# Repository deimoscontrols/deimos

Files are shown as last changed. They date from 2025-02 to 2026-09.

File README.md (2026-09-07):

# Deimos

|[Website](https://deimoscontrols.com) |\||[Control Program](https://github.com/deimoscontrols/deimos/tree/main/software/deimos) |\|| [Packet Formats](https://github.com/deimoscontrols/deimos/tree/main/software/deimos_shared) |\|| [Firmware](https://github.com/deimoscontrols/deimos/tree/main/firmware) |\|| [Hardware Designs](https://github.com/deimoscontrols/deimos/tree/main/hardware) |
|---|-|---|-|---|-|---|-----|-|

Realtime data acquisition and controls ecosystem, including hardware, firmware, and software.

Deimos DAQ hardware

# Contact

|  | Purpose |
|---|---|
| support@deimoscontrols.com <br> or <br>https://deimoscontrols.com/contact/ | Questions about the hardware or software |

# Hardware Peripherals

| Model | I/O Medium | Sample/Control Rate | Input Capabilities | Output Capabilities |
|---|---|---|---|---|
| [Deimos DAQ 7.0.x](https://deimoscontrols.com/products/deimos_daq/) | UDP/IP/Ethernet | 5Hz-8kHz measure & control<br>5Hz-500Hz Modbus<br><br>Performance depends on network and host machine | 16x analog, 6x digital | 4x PWM <br>2x analog<br>4x GPIO |
| [Deimos DAQ 8.0.x](https://deimoscontrols.com/products/specs/) | UDP/IP and Modbus/TCP over Ethernet | 5Hz-8kHz measure & control<br>5Hz-500Hz Modbus<br><br>Performance depends on network and host machine | 6x voltage, 2x thermocouple, 3x resistance, 4x 4-20mA<br>2x GPIO, 4x encoder<br>Bus current, bus voltage, and board temperature diagnostics | 4x PWM<br>2x analog<br>4x GPIO |

# Controller Comm. Media

Communication with peripherals is done via message passing on an arbitrary socket. New communication media can be used by implementing the `Socket` trait.

While the controller can accommodate multiple communication media, a peripheral will typically only implement one method for reliability reasons.

| I/O Medium | Notes |
|---|---|
| UDP/IPV4 | Nominal peripheral I/O; compared to TCP, eliminates packet storm network instability.<br><br>The controller reasserts the full peripheral state on each cycle, so while UDP allows some packet loss (typically 1e-4 or less), a change in peripheral state is never missed permanently. |
| Unix socket | Inter-process communication option for software peripheral mockups |
| Thread channel | Inter-thread communication option for software peripheral mockups |

Several more socket implementations are planned, including TCP, UDP/IPV6, and thread channel message passing.

# Data Integrations

Data integration implementations perform I/O and database transactions on a separate core to avoid blocking the main control loop, unless no separate core is available.

| Target | I/O Medium | Notes |
|---|---|---|
| CSV | Disk | Fixed-width row format.<br>Wrap, split, or terminate at end of pre-sized file. |
| DataFrame | RAM | Wrap or terminate at end of preallocated in-memory storage. |
| TimescaleDB (postgres) | TCP or unix socket | Create table & schema or reuse existing.<br>Insert individual rows or write buffered batches for increased total ingestion rate.<br>Set fixed retention duration. |
| Latest-value | RAM | Read the latest data manually from outside the control program. |

# Calculation Functions

| Name | Description | Notes |
|---|---|---|
| Controllers | | |
| SequenceMachine | A flexible state-machine where each state is defined by a time-dependent lookup table sequence with user-defined transition criteria | Allows implementation of essentially arbitrary scheduling and operational logic |
| Pid | Proportion-integral-derivative controller with anti-windup | |
| Hysteretic | Bang-bang controller with persistence counter | |
| Interpolation & Filtering | | |
| Butter | Second-order Butterworth low-pass filter | |
| Polynomial | Fast evaluation of polynomials for calibrations | Includes Levenberg-Marquardt curve-fitting utility |
| Temperature | | |
| TcKtype | K-type thermocouple tables with cold-junction correction | Highly-optimized, low-latency, embedded-compatible implementation based on ITS-90 tables |
| RtdPt100 | 100-ohm platinum RTD temperature-resistance tables | Highly-optimized, low-latency, embedded-compatible implementation based on DIN-43-760 / ITS-90 and IEC 60751 / Callender-Van Dusen |

... in addition to a variety of unremarkable math functions.

# Goals and Anti-Goals

The goals of this ecosystem are:

* Tightly-integrated sensor frontends
* _Fully independent_ input and output channels; every advertised channel is available _at the same time_
* Full reassertion of state at each control cycle; robust to packet loss
* SI-traceable calibrations
* Control program without required root/admin access or drivers
* Run on standard networking hardware with sub-microsecond time sync
* Semantic versioning for both hardware and software to prevent unexpected breaking changes
* 100% end-to-end open-source hardware, firmware, and software under permissive licenses

Notable anti-goals:

* Copyright mongering
* "Internet-of-Things" (IoT) functionality
* Over-the-Air (OTA) firmware updates
* Performative complexity
* Skimping on bits

# Versioning

To prevent unexpected breaking changes, both software and hardware use semantic versioning and, whenever possible, use procedural semver linting to avoid unexpected or unintuitive breakage.

Semantic versioning of hardware is not yet a well-established practice. Here, it is taken to cover both hardware and accompanying firmware, and their interfaces:

* Major version: Potentially breaking changes
    * Examples: Removing a channel, increasing filter phase lag, narrowing samplerate range, or changing packet interchange format, reducing overvoltage tolerance
        * Adding a channel is also a breaking change if it affects packet interchange format
    * Notable non-examples: Changing connector types for sensors without a noise-level or thermoelectric voltage sensitivity, changing model number
* Minor version: Backward-compatible changes
    * Examples: Adding a channel, increasing samplerate range, decreasing filter phase lag, increasing overvoltage tolerance
* Patch version: Forward- and backward- compatible changes
    * Examples: Updating silkscreen, changing non-sensitive connector types, swapping non-sensitive components such as decoupling capacitors

Both major and minor hardware versions are accompanied by new hardware project files. Patch hardware versions are applied to the existing hardware project files.

# License

Licensed under either of

* Apache License, Version 2.0, ([LICENSE-APACHE](LICENSE-APACHE.txt) or http://www.apache.org/licenses/LICENSE-2.0)
* MIT license ([LICENSE-MIT](LICENSE-MIT.txt) or http://opensource.org/licenses/MIT)

at your option.

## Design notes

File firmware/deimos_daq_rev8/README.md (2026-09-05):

# Deimos DAQ rev8 firmware

## Timer pinout

| Channel | Phase | Pin | Timer channel | Alternate function |
| --- | --- | --- | --- | --- |
| Encoder0 | A | PE9 | TIM1_CH1 | AF1 |
| Encoder0 | B | PE11 | TIM1_CH2 | AF1 |
| Encoder1 | A | PC6 | TIM8_CH1 | AF3 |
| Encoder1 | B | PC7 | TIM8_CH2 | AF3 |
| Encoder2 | A | PB6 | TIM4_CH1 | AF2 |
| Encoder2 | B | PB7 | TIM4_CH2 | AF2 |
| Encoder3 | A | PB4 | TIM3_CH1 | AF2 |
| Encoder3 | B | PB5 | TIM3_CH2 | AF2 |

PWM0 moves to PE6/TIM15_CH2 AF4. PWM1 through PWM3 remain on
PB14/TIM12_CH1 AF2, PB8/TIM16_CH1 AF1, and PB9/TIM17_CH1 AF1.

The calibration image is selected by `firmware/flash.py` before each build:

Calibration images contain both ADC and DAC affine coefficients. Images generated
before DAC calibration was added have a different binary layout and must be regenerated.

- If the assigned unit has a generated `calibration.bin` in its website records
  directory, the script copies it to `static/calibration.in` before building.
  The completed artifact has `firmware_calibrated = 1`.
- If that unit-specific `calibration.bin` is absent, the script removes any
  previously staged `static/calibration.in`. `build.rs` then embeds identity
  affine coefficients and sets `firmware_calibrated = 0`. This is the image to
  flash immediately before a calibration run.

The controller enforces the operational convention: calibration collection
requires the identity image, while normal Deimos operation requires the final
calibrated image. Consequently, a stale calibrated image cannot accidentally be
calibrated a second time, and an identity image cannot silently be used for
normal operation.

For an identity calibration run, use `--nocal`. This overrides an existing
generated calibration and removes any staged `static/calibration.in` before
building:

```sh
uv run python firmware/flash.py --nocal
```

For the final calibrated image, leave the generated file in its records
directory and run:

```sh
uv run python firmware/flash.py
```

Both commands are run from the repository root. `flash.py` selects the board,
probe, serial number, and MAC address from `firmware/assignments.json`.

## Encoder0 loopback validation on rev7 hardware

Run the validation through the ordinary nonblocking controller with the normal
rev8 firmware. Connect DO0 to Encoder0 A and DO1 to Encoder0 B, including the
corresponding signal reference/return connections required by the front-panel
wiring. DO0 and DO1 must remain manually writable rather than driven by calcs.

The runnable application-level procedure is
`software/deimos/examples/rev8_encoder_loopback_validation.py`. For example:

```sh
uv run --project software/deimos python \
  software/deimos/examples/rev8_encoder_loopback_validation.py
```

It uses only the existing nonblocking `RunHandle` read/write interface, emits
64 positive quadrature cycles, and requires `encoder0` to advance by 256 counts.
Every phase transition is synchronized to controller snapshots, and DO0/DO1
are restored low before the procedure returns.

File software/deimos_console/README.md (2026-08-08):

# deimos-console

Operator console viewer for Deimos realtime reporting. Joins the UDP multicast stream published by
a `ReportingDispatcher`, renders scrolling unit-labeled scope traces for configured channel groups,
writes a per-session forensic CSV log so operators can reconstruct exactly what was on screen at any
moment, and displays a connection-health indicator that turns stale when the stream goes quiet.

## Running

```sh
cargo run -p deimos_console -- --config software/deimos_console/examples/console.toml
```

Run from the repo root. The console connects automatically when the controller enters Operating
state and recovers gracefully when it restarts.

## Config file format

The config file is TOML. All fields except `multicast_group` and `port` are optional.

| Field | Type | Default | Description |
|---|---|---|---|
| `multicast_group` | IPv4 address | — | Multicast group the reporting dispatcher publishes to (e.g. `239.255.0.1`) |
| `port` | integer | — | UDP port (must match the dispatcher's configured port) |
| `interface` | IPv4 address | OS default | Local interface address to bind for multicast reception |
| `window_seconds` | float | `30.0` | Seconds of history kept in each scrolling trace |
| `staleness_threshold_secs` | float | `2.0` | Seconds without a received row before the connection-health indicator turns stale; also the per-row data-staleness threshold (viewer receipt minus controller wall clock) that drives stall detection |
| `tail_keep_secs` | float | `0.5` | Seconds of pre-stall context retained in each per-channel ring buffer when a stall fires (the rest is evicted so the live window is restored within one repaint) |
| `recovery_settle_secs` | float | `2.0` | Seconds the connection-health indicator stays in `Recovering` after a stall clears, so an operator notices the discontinuity even on a brief glance |
| `forensic_log_path` | path | none | If set, a per-session CSV is written here; rotates at 64 MiB |
| `columns` | integer | `1` | Number of columns used to lay out display panels |
| `panels` | array of `{title, channels}` | `[]` | Display panels; each renders the named channels as overlaid traces |

### Per-second telemetry tick

The console emits a `key=value` line to stderr roughly once per second so operators and post-hoc
log analysis can correlate viewer behavior with the controller's tracing output. Format:

```text
[HH:MM:SS.mmm] deimos-console: tick rows=N rate=X.YHz last_seq=N \
    wire_drops=N recv_drops=N overwritten_frames=N stalls_detected=N \
    stale_rows_evicted=N pending=N [lag_ms=min/mean/max(min/mean/max)] [(idle Ns)]
```

| Key | Meaning |
|---|---|
| `rows` | `Row` messages processed since the previous tick |
| `rate` | Rows per second over the elapsed tick interval (Hz) |
| `last_seq` | Sequence number of the most recently processed `Row`, or `-` before the first row |
| `wire_drops` | Cumulative count of sequence-number gaps observed on the wire (controller-side or network packet loss) |
| `recv_drops` | Cumulative count of messages the receiver thread could not enqueue at all — zero in steady state under drop-oldest semantics |
| `overwritten_frames` | Cumulative count of receiver-thread drop-oldest evictions; grows under sustained backpressure while preserving freshness |
| `stalls_detected` | Cumulative count of stall events fired when a drained row's lag (viewer receipt minus controller wall clock) exceeds `staleness_threshold_secs`; each event corresponds to one pre-stall buffer clear |
| `stale_rows_evicted` | Cumulative count of pre-stall samples popped from per-channel ring buffers across all stall events (forensic log retains them) |
| `pending` | Current depth of the pre-schema pending-rows queue |
| `lag_ms` | Optional per-row rx-lag triple (viewer receipt minus controller cycle-start wall clock); only present when at least one row was processed this tick |

### Threading

Buffer maintenance runs on a dedicated `deimos-console-processor` thread, not on the egui UI
thread. That thread ticks every 8 ms (125 Hz) and on each tick drains the receiver channel, runs
stall detection, evicts pre-stall samples, writes the forensic log, and emits the per-second
telemetry line. Repaint pacing (whether the window manager calls `eframe::App::update` at 60 Hz,
slower, or not at all when the window is minimized or occluded) does not affect when the buffer
moves forward. The cadence is a fixed module constant; there is no config knob.

### Example

```toml
# Sample configuration for the Deimos operator console.
# Run with: cargo run -p deimos_console -- --config software/deimos_console/examples/console.toml

# Multicast group the reporting dispatcher publishes to.
multicast_group = "239.255.0.1"

# UDP port (must match the reporting dispatcher's configured port).
port = 29573

# Outbound interface for multicast reception. Comment out to use the OS default.
# interface = "192.168.1.10"

columns = 2

[[panels]]
title = "4-20 mA Currents"
channels = [
    "p1.4_20_0_A",
    "p1.4_20_1_A",
    "p1.4_20_2_A",
    "p1.4_20_3_A",
]

[[panels]]
title = "RTD Temperatures"
channels = [
    "p1_rtd_0.temperature_K",
    "p1_rtd_1.temperature_K",
    "p1_rtd_2.temperature_K",
]

[[panels]]
title = "Thermocouple Temperatures"
channels = [
    "p1.tc_0_K",
    "p1.tc_1_K",
]

[[panels]]
title = "0-2.5 V Inputs"
channels = [
    "p1.2V5_0_V",
    "p1.2V5_1_V",
]
```

A full example lives at [`examples/console.toml`](examples/console.toml).

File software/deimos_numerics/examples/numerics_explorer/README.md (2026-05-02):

# deimos_numerics interactive examples

This is a standalone `Leptos` + `plotly.rs` client-side application for
building interactive examples directly on top of the `deimos_numerics` crate.

The scaffold is intentionally simple:

- `Leptos` manages app state and controls.
- `plotly.rs` builds figure specs in Rust.
- Plot rendering is delegated to Plotly.js in the browser.
- Each example lives in plain Rust and can call directly into `deimos_numerics`.

## Prerequisites

1. Install the wasm target:

   ```bash
   rustup target add wasm32-unknown-unknown
   ```

2. Install `trunk`:

   ```bash
   cargo install trunk
   ```

## Run

```bash
cd examples/leptos-plotly
trunk serve
```

Then open the local URL reported by `trunk`.

## Layout

- `src/app.rs`: overall shell, example catalog, and page switching
- `src/catalog.rs`: major-feature catalog used by the sidebar and home screen
- `src/examples/`: concrete example pages
- `src/plot_helpers.rs`: small shared plotting helpers for multi-trace line charts
- `src/plotly_support.rs`: thin bridge from Leptos effects to Plotly.js

## Current demos

- `Linear Algebra / Sparse Solvers`: sparse LU versus BiCGSTAB on the same shifted tridiagonal system
- `Linear Algebra / Sparse Cholesky`: sparse LLT versus LDLT on symmetric positive-definite and indefinite systems
- `Linear Algebra / Equilibration`: two-sided sparse scaling and its effect on BiCGSTAB convergence
- `Linear Algebra / Dense Eigen + SVD`: eigenvalue maps and singular spectra for self-adjoint and non-normal dense matrices
- `Linear Algebra / Gramians + HSVD`: controllability/observability Gramian spectra plus HSVD versus a plain SVD of `A`
- `LTI Analysis / Process Models`: delayed FOPDT step and Bode exploration
- `LTI Analysis / Plot Gallery`: Bode, Nyquist, Nichols, pole-zero, and root-locus inspection from one loop transfer
- `Filter Design / Low-pass`: interactive digital low-pass design, response inspection, and state-space cutoff sweeps
- `Filter Design / Savitzky-Golay`: FIR smoothing versus sliding-mean comparison with response and tap views
- `Estimation / Kalman Workbench`: recursive versus steady-state discrete Kalman filtering
- `Estimation / Nonlinear Tracking`: fixed-linearization KF versus EKF versus UKF on the same nonlinear range-tracking problem
- `Identification / OKID + ERA`: sampled I/O identification and realized-model comparison
- `Identification / Process-Model Fitting`: FOPDT and SOPDT surrogate fitting on matched and mismatched step-response data
- `Reduction / Balanced Truncation`: HSV spectrum plus full/reduced step-response comparison
- `Synthesis / PID Design`: SIMC and frequency-domain PID tuning across process models and a higher-order linear plant
- `Synthesis / Discrete LQR`: open-loop versus closed-loop sampled regulation

## Adding a new example

1. Add a new `ExampleId` + catalog entry in `src/catalog.rs`.
2. Add a page component under `src/examples/`.
3. Register the page in `src/examples/mod.rs`.
4. Add a `match` arm in `src/app.rs`.

The existing pages are the reference patterns for:

- control-panel signals
- derived plot generation
- calling `deimos_numerics` directly from UI logic
- rendering Plotly figures from Rust

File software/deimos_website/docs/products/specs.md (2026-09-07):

# Deimos DAQ - Specs

Specifications refer to performance including applied calibrations.<br>
Values are preliminary and may be adjusted as further test data is collected.

| Feature | Performance |
|---|---|
| Comm. Medium | Ethernet. |
| Power Supply | 24V DC 1A |
| Cycle Rate | 5 Hz - 8000 Hz over Deimos/UDP. <br>5 Hz - 500 Hz over Modbus/TCP. |
| Multi-Unit Time Sync | ~1 microsecond (100ns typ.) |
| Sample Jitter | 0.01% of Δt |
| Voltage Reference | 0.02% accuracy, ultra-low thermal sensitivity. |
| ADCs | 16-bit SAR, self-calibrating. |
| Internal Samplerate | Nominal 9kHz delayed-simultaneous sampling.<br>Adjusted to synchronize with the reporting rate.<br>See [dynamics page](./dynamics.md#internal-samplerate-variation) for details. |
| Onboard Filtering | Every analog channel has:<br>- Active analog filter.<br>- Digital anti-aliasing filter.<br>- Digital sample synchronization filter. |

## :material-controller-classic:{ .lg .middle } Outputs

| Kind | Range | Resolution | Notes |
|---|---|---|---|
| :material-square-wave: 4x PWM  | 1Hz-100kHz | 16-bit | Independent frequencies and duty cycles.<br>40Ω termination. |
| :material-square-wave: 4x GPIO Output |  | 1-bit | 40Ω termination. |
| :material-sine-wave: 2x DAC (Voltage) | 0-2.5V | 12-bit (0.6mV) | Buffered & calibrated to 0.01%. |

## :material-ear-hearing:{ .lg .middle } Inputs

| Kind | Range | Accuracy | Resolution | Notes |
|---|---|---|---|---|
| :material-lightning-bolt: 2x Voltage, 0-2.5V | 0-2.5V | 0.01% | 38uV | Single-ended.<br>±40V tolerance.  |
| :material-lightning-bolt: 2x Voltage, 0-15V | 0-15V | 0.01% | 228uV | Single-ended.<br>±40V tolerance.<br>12kOhm divider; 0.6mA max leakage.<br>Calibrated range is 0-10V. |
| :material-lightning-bolt: 2x Voltage, ±35mV | -39mV to +55mV | 0.1% | 1.5uV | Single-ended.<br>±40V tolerance. |
| :material-fire: 2x K-Type Thermocouple | 73-1543K | 0.3K | 0.04K | Cold-junction compensated.<br>Material-matched connector.±40V tolerance. |
| :material-snowflake: 3x 3-Wire Resistance (RTD, strain, etc) | 73-1073K | 0.1K | 0.02K | Specs refer to use with Pt100 RTD.<br>Also compatible with 100-ohm strain gauges. |
| :fontawesome-solid-gauge-high: 4x 4-20mA | 0-33mA | 0.01% | 0.8uA | 24V excitation.<br>2 or 3-wire.<br>Short-circuit protected. |
| :material-square-wave: 2x GPIO Input |  | 1-bit | ±40V tolerance. |
| :material-square-wave: 4x Encoder | |  | | Signed 64-bit accumulator.<br>Forward/backward counting.<br>±40V tolerance. |
| :material-thermometer: Diagnostics | ||| Bus current.<br>Bus voltage.<br>Board / cold-junction temp. |

## :material-gauge-full:{ .lg .middle } Benchmarks

The operating space of the Deimos DAQ is one-dimensional: everything is a function of cycle rate.

The following benchmark data is collected using a consumer laptop host machine
running ubuntu linux with a low-latency usb-to-ethernet adapter.

Networking hardware with added latency can limit maximum cycle rate. As a result,
this system performance is typical, but is not guaranteed.

<div class="bode-plot-frame rate-sweep-plot-frame">
  
  <iframe
    class="bode-plot"
    src="../../assets/rev7_rate_sweep_light.html"
    data-theme-src-dark="../../assets/rev7_rate_sweep_dark.html"
    data-theme-src-light="../../assets/rev7_rate_sweep_light.html"
    title="Deimos DAQ Rev7 cycle-rate benchmark"
    loading="lazy"
    onload="this.closest('.bode-plot-frame').classList.add('bode-plot-frame--loaded')"
  ></iframe>
</div>

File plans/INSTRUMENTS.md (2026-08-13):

# Third-party instrument integration design

## Scope

Third-party laboratory instruments'`Peripheral` plugin implementations under `deimos::peripheral::instruments`.

## Goals

- Make instrument inputs and outputs available in the control loop.
- Expose only the minimum required functions.
- Keep blocking I/O away from the control loop.
- Fail safely and observably.
- Keep dependencies and complexity small.
- Provide a repeatable pattern for future instrument integrations.

## Non-goals

- Hard-realtime or phase-synchronized instrument I/O.
- Complete coverage of a vendor's remote-control API.
- A single transport or protocol abstraction that covers every instrument.
- A general framework for instrument interfaces.

## Architecture

```text
                         control-process boundary

  Controller
      |
      | Deimos bind/configure/operating packets
      v
  ThreadChannelSocket
      |
      v
  protocol responder thread
      |                         ^
      | latest request          | latest completed state
      v                         |
  instrument I/O worker thread
      |
      | instrument protocol over its external transport
      v
  third-party instrument
```

Each instrument integration has four parts:

1. A `Peripheral` implementation defines identity, channel names packet codecs, validation, and standard calculations.
  * It owns no socket, thread, mutex, or live connection.
2. A protocol responder implements the software side of the normal Deimos Binding, Configuring, and Operating lifecycle over a thread channel. 
  * It must drain controller packets promptly and never perform blocking external I/O.
3. An instrument worker owns the external connection and protocol state.
4. A run handle owns stop signals and thread joins.
  * The control-program builder that starts the driver retains this handle and shuts it down after the controller stops.

The split between protocol responder and instrument worker is required to prevent blocking instrument I/O from causing deadline misses.

## Module boundaries

Instrument code lives below:

```text
deimos::peripheral::instruments
├── responder                 shared private lifecycle and registration helpers
├── scpi                      shared public settings and private TCP transport
└── <instrument>              one module per supported integration
    ├── config                public instrument configuration
    ├── peripheral            serializable controller-side representation
    ├── proxy                 device-side responder adapter
    └── driver                live state and instrument communication
```

The `peripheral` module exposes the `instruments` namespace but does not re-export concrete instrument module internals.

Each concrete instrument module exposes an `attach(name, config, &mut controller) -> RunHandle` helper that registers the peripheral, adds a one-to-one thread socket keyed by the instrument model and logical serial number, and starts the instrument driver.

Instrument model numbers occupy an explicitly documented software-only range and never overlap hardware model numbers.

## Transport and protocol rules

Each integration uses the simplest reliable transport and protocol supported by the instrument.

Addresses, connection settings, timeouts, and response limits are explicit configuration.

SCPI integrations group their shared network, identity, and timeout settings in `ScpiTcpConfig`.

Where the instrument provides an identity query, the worker verifies and logs the configured identity.

Only the instrument worker may access its connection.

## Operating lifecycle

### Startup

1. Construct the `Peripheral`, driver configuration, and driver.
2. Add one identity-keyed `ThreadChannelSocket` and peripheral to the controller.
3. Start the driver with the controller context.
  * Connect, verify identity, and enforce safe state.
5. Enter Binding only after instrument setup succeeds.
6. Scan, bind, etc. via the controller.

Startup failure returns an error before controller operation begins.

### Operation

The protocol responder acknowledges every valid controller request using the latest completed instrument state.

Instruments may run at a lower rate than the controller.

Each instrument worker uses the enforcement strategy appropriate for that instrument. It may compare the latest commanded state with the last completed state and transmit only required changes, or it may reassert the complete state.

### Shutdown

Controller termination first emits its normal zero-valued peripheral inputs.

The worker then makes a bounded best-effort attempt to enforce safe state, stop acquisition, and close its connection.

Dropping a run handle signals all integration threads; joining reports panics and latched worker errors.

Shutdown never waits forever for an unresponsive instrument.

## Timing semantics

Instrument data is asynchronous and has loose, host-observed timing:

- Outputs become applied when the external operation completes.
- An acquired value is timestamped with the best available information.

## Failure and safety policy

- Clamp source commands to explicitly configured limits. NaN maps to safe-state.
- Limits, safe states, and expected identity are explicit configuration.
- Error on startup identity mismatch.
- A timeout, disconnect, malformed response, or invalid acquired value latches a driver error.
  * The proxy ceases valid operating responses so the existing controller loss-of-contact policy terminates the run.
- Errors identify the instrument and operation but never substitute a plausible value for invalid or missing data.
- Instruments use a documented safe configuration unless supplied by the caller.
- Only one Deimos driver owns a given instrument control connection.

## Testing policy

Automated tests use a HOOTL mockup. No laboratory hardware or network discovery required.

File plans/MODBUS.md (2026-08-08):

# Modbus/TCP design

## Scope

The DAQ has two operating states:

- `OperatingDeimos` exchanges synchronous UDP command/snapshot roundtrips with
  the Deimos controller.
- `OperatingModbus` exposes the same measurements and retained outputs through
  one Modbus/TCP connection.

Both call the same `Board::operate` implementation. Acquisition, filtering,
calibration, conversion, timing, and output handling therefore remain
protocol-independent.

```text
Connecting -> Binding -> Configuring -> OperatingDeimos
                    \
                     +-- valid Modbus request -> OperatingModbus

OperatingDeimos -- loss of contact --> Connecting
OperatingModbus -- loss of contact --> Connecting
OperatingModbus -- cycle-rate change --> OperatingModbus(new configuration)
```

A valid FC03, FC04, FC16, or FC23 request in `Binding` selects Modbus operation.
The request is retained and answered from the first operating snapshot, so a
read-only client can start Modbus mode. If UDP binding wins, the TCP listener is
closed before Deimos configuration.

## Shared measurement path

`OperatingSnapshot` is the source for both the Deimos response and Modbus
register image. It contains final engineering values, device I/O, acquisition
time, publication time, and operating metrics.

`sample_time_ns` identifies the start of the contributing ADC group, while
`metrics.sent_time_ns` identifies publication.
`metrics.id` provides snapshot ordering.

Every read within a publishing cycle sees the same immutable snapshot.

Calibration and engineering conversions run in firmware in both modes.

Reusable no-std calculations live in `deimos_shared`.

Devices report their calibration state during configuration and reject
Modbus operation when a required calibration is absent.

Calibration is not writable except by flashing the firmware.

Firmware latches one engineering snapshot per publishing cycle before network processing.

Protocol handling never advances acquisition or filters.

Each snapshot begins with a device-specific magic value.

Receive paths validate lengths, identity, enums, and safety-relevant ranges
before changing state or outputs.

## Module boundaries

Each `deimos_shared::peripherals` device module is the no-std source of truth
for packets, register maps, codecs, and validation shared between firmware and
software.

## Modbus/TCP behavior

### Transport and framing

Firmware listens on TCP port 502 while in `Binding`.
It supports one client and accepts every Unit Identifier, including 0 and 255.

Device register maps use zero-based protocol addresses.

Firmware stages the six-byte MBAP prefix, validates its declared length, and
reads through exactly one ADU.

Fragmented ADUs remain buffered across cycles; pipelined ADUs stay aligned.

Invalid protocol IDs or impossible lengths close only that connection.

Request and response storage is fixed at 256 bytes.

`rmodbus` handles FC03, FC04, and FC16. FC23 is local until `rmodbus` implements it.

### Functions and errors

- FC03 reads holding registers (config, outputs, and diagnostics).
- FC04 reads input registers (measurements).
- FC16 atomically writes complete holding fields.
- FC23 atomically writes one holding block and reads another in one ADU.

Unsupported functions return `Illegal Function`.
Read-only, split-field, cross-gap, and out-of-range accesses return `Illegal Data Address`.
Invalid values return `Illegal Data Value`.

Writes are validated as a complete candidate before application.

### Retained state and loss of contact

Each device defines its default publishing rate, timeout, and safe outputs.

Successful writes retain output values until replaced.

Any accepted modbus request resets the loss-of-contact counter.

Invalid requests do not reset loss of contact.

Loss-of-contact timeout returns the device to Connecting and safe outputs.

Period correction persists and phase correction applies once.
Firmware clamps applied corrections to preserve cycle timing margin.

## Synchronized control

FC23 is the preferred cyclic transaction. This combines:

- bulk-read the device's complete coherent snapshot mirror (sensor readings)
- bulk-write the complete set of output values (PWM, etc.) and timing adjustment

Configuration registers (cycle dt, timeout, etc.) should be written and read
only as needed, not on every cycle.

If two ADUs are handled in one cycle, both read the same snapshot.

If the FC23 reads and writes the same block, the read will reflect the previous write.

## Realtime bounds

Each Binding or Modbus operating cycle permits at most:

- two complete ADU parses;
- four TCP receive-buffer calls;
- four TCP transmit-buffer calls;
- two Ethernet-frame receives; and
- two Ethernet-frame transmits.

Each ADU uses at most two receive and two transmit calls.

TCP backpressure blocks consumption of the following request
until the response enters the TX ring.

Two ADUs per cycle allow a short backlog to drain.
Cyclic clients should keep one FC23 request outstanding.

## Operational constraints

- Use Modbus/TCP only on a trusted control network; it has no authentication or
  encryption.
- Connect one client and normally keep one FC23 request outstanding.
- Read the complete device snapshot block for synchronized measurements.

## References

1. Modbus Organization, *MODBUS Application Protocol Specification V1.1b3*, 2012.
2. Modbus Organization, *MODBUS Messaging on TCP/IP Implementation Guide V1.0b*, 2006.

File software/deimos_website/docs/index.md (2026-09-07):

---
hide:
  - toc
  - navigation
---

#

<!-- Hachyderm verification -->
<link rel="me" href="https://hachyderm.io/@deimoscontrols">

<section class="home-hero">
  <div class="home-hero__intro">
    <p class="home-hero__eyebrow">Open-Source Ethernet DAQ and Control Hardware</p>
    <h2>Accuracy, Speed, Control.<br><b><i>Pick three.</i></b></h2>
    <p class="home-hero__lede">
      Deimos DAQ is your interface between software and hardware: measurement and real-time controls integrated in a single ethernet-connected
      package. 
    </p>
    <div class="home-hero__actions">
      <a class="md-button md-button--primary" href="products/deimos_daq/">View Product</a>
      <a class="md-button" href="products/specs/">Read Specs</a>
    </div>
    <dl class="home-hero__facts">
      <div>
        <dt>Cycle rate</dt>
        <dd>5 Hz - 8 kHz</dd>
      </div>
      <div>
        <dt>Inputs</dt>
        <dd>22 channels</dd>
      </div>
      <div>
        <dt>Outputs</dt>
        <dd>10 channels</dd>
      </div>
    </dl>
  </div>

  <aside class="home-cta" aria-labelledby="home-cta-title">
    <div class="daq-photo-stack">
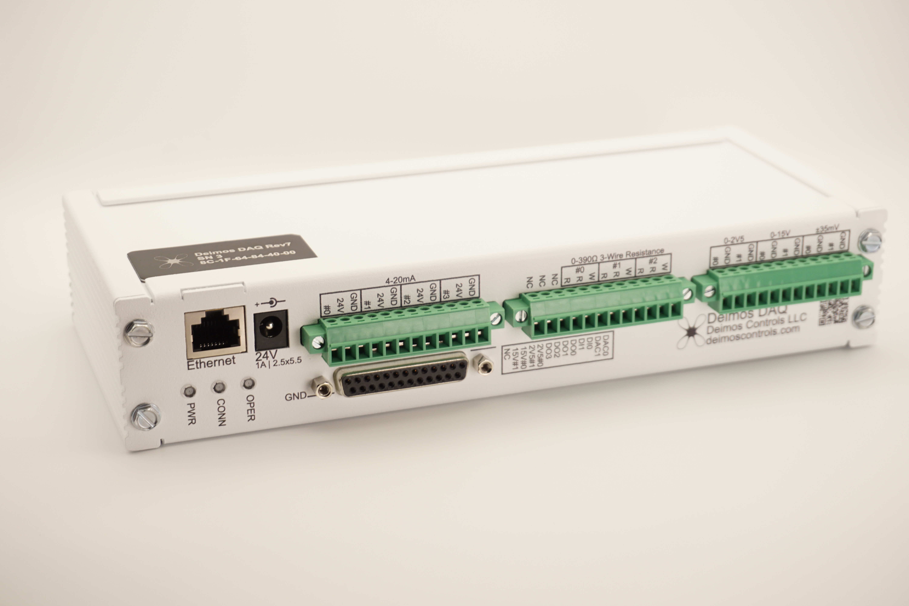
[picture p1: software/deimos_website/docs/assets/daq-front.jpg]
Deimos DAQ front view with Ethernet, power, and analog inputs
      
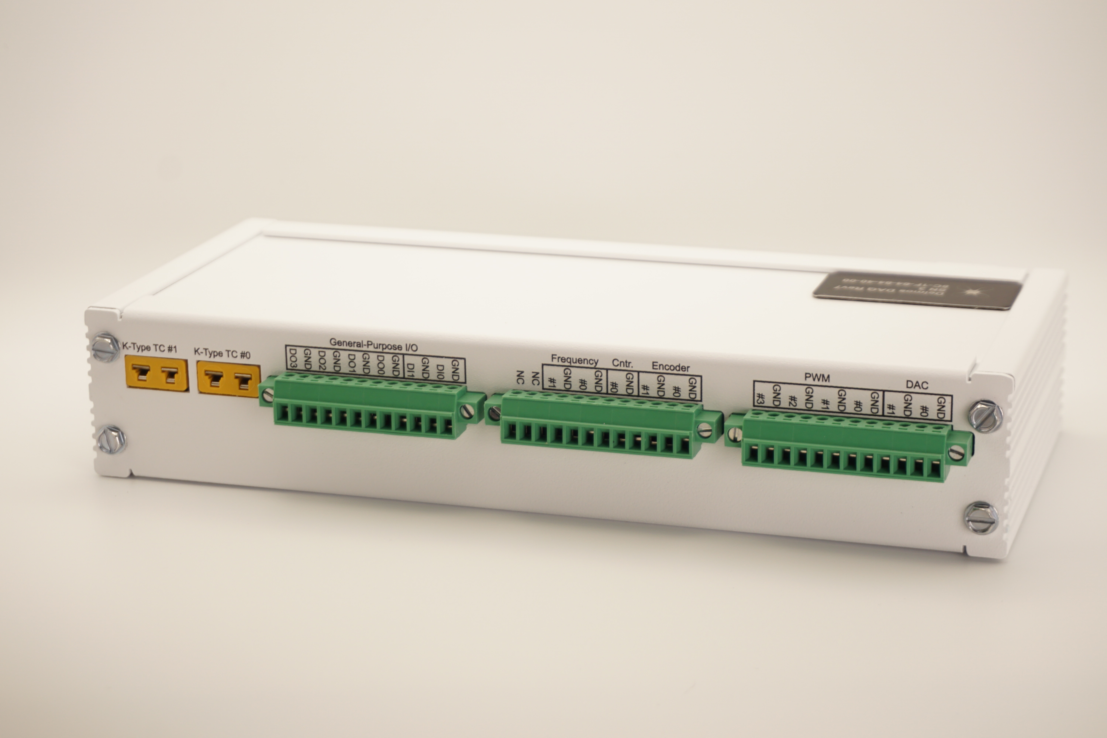
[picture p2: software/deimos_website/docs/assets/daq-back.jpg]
Deimos DAQ back view with thermocouple, digital, PWM, and DAC connections
      
    </div>
    <div class="home-cta__body">
      <p class="home-cta__eyebrow">Pre-launch updates</p>
      <h2 id="home-cta-title">Follow development and availability.</h2>
      <p>
        Follow the project on Crowd Supply for development updates and to be the
        first to hear when units are in stock and ready to ship!
      </p>
      <!-- Temporarily hidden until after the Crowd Supply launch. -->
      <form
        class="home-signup"
        action="https://deimoscontrols.us13.list-manage.com/subscribe/post?id=62e300351a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"
        method="post"
        target="home-mailchimp-target"
        hidden
      >
        <label for="home-signup-email">Email</label>
        <div class="home-signup__row">
          <input id="home-signup-email" type="email" name="EMAIL" autocomplete="email" required>
          <button type="submit" class="md-button md-button--primary">Sign Up</button>
        </div>
        <input type="text" name="b_d3f613c56803a4b84867251d4_62e300351a" tabindex="-1" value="" hidden>
      </form>
      <iframe
        id="home-mailchimp-target"
        name="home-mailchimp-target"
        title="Mailing list signup target"
        hidden
      ></iframe>
      <a class="home-cta__crowd-supply md-button md-button--primary" href="https://www.crowdsupply.com/deimos-controls/deimos-daq" rel="noopener" target="_blank">
        Follow on Crowd Supply
      </a>
      <p>
        Interested in beta-testing? Reach out via the <a href="contact/">contact page</a>!
      </p>
    </div>
  </aside>
</section>

<section class="home-section">
  <!-- <h2>[Write a heading for what Deimos DAQ helps people do.]</h2> -->
  <div class="home-feature-grid">
    <article class="home-feature">
      <h3>Data Acquisition</h3>
      <p>Integrated analog frontends make best-in-class data quality.</p>
    </article>
    <article class="home-feature">
      <h3>Controls</h3>
      <p>Multi-module synchronized control, right out of the box.</p>
    </article>
    <article class="home-feature">
      <h3>Open Source</h3>
      <p>Full transparency from hardware to firmware to software.</p>
    </article>
  </div>
</section>

<section class="home-section home-section--split">
  <div>
    <p class="home-cta__eyebrow">Data Quality</p>
    <p>
      Meticulous signal processing threads the needle to eliminate noise while
      retaining a tight control response.<br><br>
      Every analog channel has an active analog anti-aliasing filter backed by a
      digital filter pipeline that is automatically adjusted for your chosen reporting rate.<br><br>
      All filters and transfer functions are detailed in the specs and available as open-source software.
    </p>
    <a class="md-button" href="products/frontends/">Explore Frontends</a>
  </div>
  Sallen-Key filter schematic
</section>

<!-- <section class="home-section">
  <p class="home-cta__eyebrow">Measure everything, control anything</p>
  <div class="home-use-cases">
    <a class="home-use-case" href="usecases/turbine/">
      <span>Fluid Systems</span>
      <img src="assets/usecase_turbine.svg" alt="Fluid systems use-case diagram" class="zoomable-image">
    </a>
    <a class="home-use-case" href="usecases/motor/">
      <span>Electric Motors</span>
      <img src="assets/usecase_motor.svg" alt="Electric motors use-case diagram" class="zoomable-image">
    </a>
    <a class="home-use-case" href="usecases/plating/">
      <span>Chemical Processing</span>
      <img src="assets/usecase_processing.svg" alt="Chemical processing use-case diagram" class="zoomable-image">
    </a>
  </div>
</section> -->

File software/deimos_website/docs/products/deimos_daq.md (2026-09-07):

---
hide:
- toc
---

#

## :material-graph-outline:{ .lg .middle } Overview

<div class="product-visuals">
  <div class="daq-photo-stack">
    Deimos DAQ front view with Ethernet, power, and analog inputs
    Deimos DAQ back view with thermocouple, digital, PWM, and DAC connections
  </div>
  Deimos DAQ connection diagram
</div>

The Deimos DAQ boasts a set of 22 input channels and 10 output channels,
all available together and operated simultaneously on every cycle.

Fully open-source, the Deimos DAQ's design files, firmware, and control program can all be
found under permissive licenses in the [Deimos project repository](https://github.com/deimoscontrols/deimos).

See the [specs page](./specs.md) for steady performance, and [dynamics page](./dynamics.md) for filter characteristics.

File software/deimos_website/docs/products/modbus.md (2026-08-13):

# Deimos DAQ Rev7 Modbus/TCP register map

Addresses are zero-based protocol addresses. Multi-register scalars place
the most-significant 16-bit register first, and registers use network byte
order. `f32` fields contain IEEE-754 bits; signed integers use two's
complement.

## Input registers (FC04)

Read address 0, count 75 for one coherent engineering snapshot. Partial
in-range reads are supported, but the full block is the synchronized-sample
contract.

| Address | Count | Type | Field | Units / shape |
| ---: | ---: | --- | --- | --- |
| 0 | 2 | `u32` | `magic` | `0xD7000002` |
| 2 | 4 | `u64` | `metrics.id` | snapshot count |
| 6 | 4 | `i64` | `metrics.sent_time_ns` | ns |
| 10 | 4 | `u64` | `metrics.last_input_id` | last accepted transaction ID |
| 14 | 4 | `i64` | `metrics.last_input_received_time_ns` | ns |
| 18 | 4 | `i64` | `metrics.cycle_time_margin_ns` | ns |
| 22 | 4 | `i64` | `sample_time_ns` | acquisition start, ns |
| 26 | 2 | `f32` | `module_bus_current_a` | A |
| 28 | 2 | `f32` | `module_bus_voltage_v` | V |
| 30 | 2 | `f32` | `board_temperature_k` | K |
| 32 | 8 | `f32[4]` | `current_4_20_a` | A, channels 0..3 |
| 40 | 6 | `f32[3]` | `rtd_resistance_ohm` | ohm, channels 0..2 |
| 46 | 4 | `f32[2]` | `thermocouple_temperature_k` | K, channels 0..1 |
| 50 | 12 | `f32[6]` | `voltage_v` | V, channels 0..5 |
| 62 | 4 | `i64` | `encoder` | counts |
| 66 | 4 | `i64` | `pulse_counter` | counts |
| 70 | 4 | `f32[2]` | `frequency_meas` | Hz, channels 0..1 |
| 74 | 1 | `u16` | `gpio` | input bits 0..1 |

`sample_time_ns` is captured before the first ADC conversion group
contributing to the snapshot. It is not corrected for fractional-delay or
low-pass-filter group delay.

## Holding registers (FC03, FC16, and FC23)

Read address 0, count 35 for the complete configuration and diagnostic
block. FC03 may read any in-range block. FC16 and the write portion of FC23
must cover complete fields within one writable block: base configuration
(0..2), outputs (6..26), or timing corrections (27..34).

| Address | Count | Access | Type | Field | Valid values |
| ---: | ---: | --- | --- | --- | --- |
| 0 | 2 | R/W | `f32` | cycle rate | finite, 5..500 Hz |
| 2 | 1 | R/W | `u16` | loss-of-contact limit | 1..65535 cycles |
| 3 | 2 | R | `u32` | current cycle period | ns |
| 5 | 1 | R | `u16` | current loss counter | cycles |
| 6 | 8 | R/W | `f32[4]` | PWM duty fractions | finite, 0..1 |
| 14 | 8 | R/W | `u32[4]` | PWM frequencies | nonzero Hz |
| 22 | 4 | R/W | `f32[2]` | DAC voltages | finite, 0..2.5 V |
| 26 | 1 | R/W | `u16` | GPIO outputs | bits 0..3 only |
| 27 | 4 | R/W | `i64` | requested period delta | ns; persistent, internally clamped |
| 31 | 4 | R/W | `i64` | requested phase delta | ns; one cycle, internally clamped |

The coherent snapshot is mirrored in read-only holding registers 256..330
(`0x0100`..`0x014A`) with the same layout as input registers 0..74. Writes
to the mirror or the unsupported gap at 35..255 return `Illegal Data
Address`.

## Synchronized control (FC23)

FC23 Read/Write Multiple Registers is the recommended cyclic interface.

Read address 256, count 75 while writing one complete writable block. The
response contains the most recent snapshot; accepted outputs are applied afterward. Does not return configuration registers 0..34.

If two ADUs are serviced in one cycle, both return the same snapshot, and both writes are applied in order and committed in the final combined state. Omitted fields retain their values; rejected writes change nothing.

Period correction persists until replaced, while phase correction applies once and then is cleared for the next cycle.
Timing corrections are clamped to +/-10% of the nominal period.

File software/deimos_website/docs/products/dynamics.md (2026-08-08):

---
hide:
- toc
---

## :material-chart-bell-curve:{ .lg .middle } Frontends

Each analog input has a filter pipeline that improves data quality while
accommodating bandwidth requirements for common applications.

Digital IIR filters are adapted internally to target a cutoff frequency of 0.4x the
cycle rate up to a 4500Hz cycle rate.

Above 4500Hz cycle rate, the digital antialiasing filter is disabled
and antialiasing relies on frontend analog cutoff.

| Kind | Frontend Cutoff | Target Use-Cases |
|---|---|---|
| Board temperature | 100Hz | - Cold-junction correction.<br>- System health. |
| Bus voltage | No frontend | System health. |
| Bus current | No frontend | System health. |
| 0-2.5V | 3kHz | General-purpose |
| 0-15V | 3kHz | 0-10V sensor inputs. |
| ±35mV | 1kHz | Low-noise measurement of small signals. |
| 3-Wire Resistance | 3kHz | - Pt100 RTD temperature.<br>- 100-ohm strain gauges.|
| K-type Thermocouple | 1kHz | Fast responses and high maximum temperature. |
| 4-20mA | 3kHz | - Pressure transducers.<br>- Valve angle feedback.

## 100Hz Analog (Board Temperature)

  <div class="bode-plot-frame">
    
    <iframe
      class="bode-plot"
      src="../../assets/rev7_bode_100hz_frontend_light.html"
      data-theme-src-dark="../../assets/rev7_bode_100hz_frontend_dark.html"
      data-theme-src-light="../../assets/rev7_bode_100hz_frontend_light.html"
      title="Deimos DAQ Rev7 100Hz analog frontend Bode plot"
      loading="lazy"
      onload="this.closest('.bode-plot-frame').classList.add('bode-plot-frame--loaded')"
    ></iframe>
  </div>

## 1kHz Analog

  <div class="bode-plot-frame">
    
    <iframe
      class="bode-plot"
      src="../../assets/rev7_bode_1khz_frontend_light.html"
      data-theme-src-dark="../../assets/rev7_bode_1khz_frontend_dark.html"
      data-theme-src-light="../../assets/rev7_bode_1khz_frontend_light.html"
      title="Deimos DAQ Rev7 1kHz analog frontend Bode plot"
      loading="lazy"
      onload="this.closest('.bode-plot-frame').classList.add('bode-plot-frame--loaded')"
    ></iframe>
  </div>

## 3kHz Analog

  <div class="bode-plot-frame">
    
    <iframe
      class="bode-plot"
      src="../../assets/rev7_bode_3khz_frontend_light.html"
      data-theme-src-dark="../../assets/rev7_bode_3khz_frontend_dark.html"
      data-theme-src-light="../../assets/rev7_bode_3khz_frontend_light.html"
      title="Deimos DAQ Rev7 3kHz analog frontend Bode plot"
      loading="lazy"
      onload="this.closest('.bode-plot-frame').classList.add('bode-plot-frame--loaded')"
    ></iframe>
  </div>

## Internal Samplerate Variation

The internal samplerate nominally targets 9kHz and adjusts to synchronize to a multiple
of the cycle rate, and to protect margin to worst-case execution time.

  <div class="bode-plot-frame">
    
    <iframe
      class="bode-plot"
      src="../../assets/rev7_samplerate_light.html"
      data-theme-src-dark="../../assets/rev7_samplerate_dark.html"
      data-theme-src-light="../../assets/rev7_samplerate_light.html"
      title="Deimos DAQ Rev7 internal samplerate versus reporting rate"
      loading="lazy"
      onload="this.closest('.bode-plot-frame').classList.add('bode-plot-frame--loaded')"
    ></iframe>
  </div>

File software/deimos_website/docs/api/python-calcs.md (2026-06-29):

# 

::: deimos.calc
    options:
      show_root_heading: true
      show_root_full_path: false
      heading_level: 2
      show_source: false
      members:
        - Affine
        - Butter2
        - Constant
        - InverseAffine
        - Pid
        - Polynomial
        - RtdPt100
        - SequenceMachine
        - Sin
        - TcKtype

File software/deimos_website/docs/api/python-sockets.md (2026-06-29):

# 

::: deimos.socket
    options:
      show_root_heading: true
      show_root_full_path: false
      heading_level: 2
      show_source: false
      members:
        - ThreadChannelSocket
        - UdpSocket
        - UnixSocket

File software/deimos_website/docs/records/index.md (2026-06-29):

# Records

Calibration reports and similar documents for each serialized unit.

{{ pagetree(children) }}

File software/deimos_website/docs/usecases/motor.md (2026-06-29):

---
hide:
- toc
---

# Use-Case: Switched Motor Development

This example shows a notional 3-phase switched motor control test assembly with a
simplified externally-actuated high-side driver.

Switched motor development use-case diagram

In this arrangement, a single DAQ unit has adequate capability to measure and control both the test article
and the supporting lab utilities. The test article, operator, and lab equipment would typically be
in a single room, but may be separated for safety depending on circumstances.

For more advanced motor controller topologies, **additional DAQs can be incorporated and time-synchronized** 
with no extra networking equipment or additional configuration - synchronization is the default, not a bonus feature.

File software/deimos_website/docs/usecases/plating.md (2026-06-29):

---
hide:
- toc
---

# Use-Case: Electroplating

A simple but effective electroplating rig is shown in the example schematic below,
operated and monitored by a single Deimos DAQ.

Electroplating use-case diagram

Etching and deposition baths can be organized similarly with chemistry and current control,
and plently of channels left over for additional features like temperature control,
colorimetry, and actuation of the workpiece or cathode.

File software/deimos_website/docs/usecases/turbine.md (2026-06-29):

---
hide:
- toc
---

# Use-Case: Turbine Engine R&D

In this example, two Deimos Analog I units provide simultaneous remote monitoring and actuation for both the fluid supply
and turbine engine test article from a test control room at a third location.

The **broad set of inputs and outputs** of each DAQ support measurement of temperatures, pressures, flowrates, and speeds
along with PWM and voltage outputs in a single module that is **simple, inexpensive, and alleviates configuration burden**
compared to conventional fragmented backplane systems.

Turbine engine R&D use-case diagram

This allows respecting a generous minimum safe distance between three mutually-incompatible areas

* Stored flammables and pressurant (the tank farm)
* Stored energy and ignition sources (the test article)
* Personnel and data storage (the control room)

within a single time-synchronization domain that supports both **precise performance measurements** under nominal operating conditions
and **rapid resolution of anomaly investigations**.

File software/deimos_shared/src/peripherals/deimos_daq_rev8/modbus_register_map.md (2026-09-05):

## Modbus/TCP register map

Addresses are zero-based protocol addresses. Multi-register scalars place
the most-significant 16-bit register first, and registers use network byte
order. `f32` fields contain IEEE-754 bits; signed integers use two's
complement.

### Input registers (FC04)

Read address 0, count 79 for one coherent engineering snapshot. Partial
in-range reads are supported, but the full block is the synchronized-sample
contract.

| Address | Count | Type | Field | Units / shape |
| ---: | ---: | --- | --- | --- |
| 0 | 2 | `u32` | `magic` | `0xD8000002` |
| 2 | 4 | `u64` | `metrics.id` | snapshot count |
| 6 | 4 | `i64` | `metrics.sent_time_ns` | ns |
| 10 | 4 | `u64` | `metrics.last_input_id` | last accepted transaction ID |
| 14 | 4 | `i64` | `metrics.last_input_received_time_ns` | ns |
| 18 | 4 | `i64` | `metrics.cycle_time_margin_ns` | ns |
| 22 | 4 | `i64` | `sample_time_ns` | acquisition start, ns |
| 26 | 2 | `f32` | `module_bus_current_a` | A |
| 28 | 2 | `f32` | `module_bus_voltage_v` | V |
| 30 | 2 | `f32` | `board_temperature_k` | K |
| 32 | 8 | `f32[4]` | `current_4_20_a` | A, channels 0..3 |
| 40 | 6 | `f32[3]` | `rtd_resistance_ohm` | ohm, channels 0..2 |
| 46 | 4 | `f32[2]` | `thermocouple_temperature_k` | K, channels 0..1 |
| 50 | 12 | `f32[6]` | `voltage_v` | V, channels 0..5 |
| 62 | 16 | `i64[4]` | `encoder` | counts, channels 0..3 |
| 78 | 1 | `u16` | `gpio` | input bits 0..1 |

`sample_time_ns` is captured before the first ADC conversion group
contributing to the snapshot. It is not corrected for fractional-delay or
low-pass-filter group delay.

### Holding registers (FC03, FC16, and FC23)

Read address 0, count 35 for the complete configuration and diagnostic
block. FC03 may read any in-range block. FC16 and the write portion of FC23
must cover complete fields within one writable block: base configuration
(0..2), outputs (6..26), or timing corrections (27..34).

| Address | Count | Access | Type | Field | Valid values |
| ---: | ---: | --- | --- | --- | --- |
| 0 | 2 | R/W | `f32` | cycle rate | finite, 5..500 Hz |
| 2 | 1 | R/W | `u16` | loss-of-contact limit | 1..65535 cycles |
| 3 | 2 | R | `u32` | current cycle period | ns |
| 5 | 1 | R | `u16` | current loss counter | cycles |
| 6 | 8 | R/W | `f32[4]` | PWM duty fractions | finite, 0..1 |
| 14 | 8 | R/W | `u32[4]` | PWM frequencies | nonzero Hz |
| 22 | 4 | R/W | `f32[2]` | DAC voltages | finite, 0..2.5 V |
| 26 | 1 | R/W | `u16` | GPIO outputs | bits 0..3 only |
| 27 | 4 | R/W | `i64` | requested period delta | ns; persistent, internally clamped |
| 31 | 4 | R/W | `i64` | requested phase delta | ns; one cycle, internally clamped |

The coherent snapshot is mirrored in read-only holding registers 256..334
(`0x0100`..`0x014E`) with the same layout as input registers 0..78. Writes
to the mirror or the unsupported gap at 35..255 return `Illegal Data
Address`.

### Synchronized control (FC23)

FC23 Read/Write Multiple Registers is the recommended cyclic interface.
Read address 256, count 79 while writing one complete writable block. The
response contains the snapshot captured at the beginning of that publishing
cycle; accepted outputs are applied afterward. It does not also return
configuration registers 0..34.

If two ADUs are serviced in one cycle, both return the same snapshot. Their
writes compose in TCP order, and firmware applies the final retained output
state after request service. Omitted fields retain their values; rejected
writes change nothing. Period correction persists until replaced. Phase
correction applies to the next publication interval and then reads as zero.
Applied timing corrections are clamped to +/-10% of the nominal period.

### Configuration readback (FC23)

A separate FC23 may write one complete configuration block and read an
in-range portion of holding registers 0..34. The read reflects the preceding
write. This transaction returns configuration and diagnostics, not the
snapshot mirror.

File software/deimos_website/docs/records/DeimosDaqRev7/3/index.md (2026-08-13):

# DeimosDaqRev7 SN 3 Records

## Calibration Record

- [Calibration JSON](<cal.json>)

## Calibration Reports

| Instrument | Channel | Report |
| --- | --- | --- |
| 0-15 V channel 0 (ain16) | `ain16` | [Dark](<deimos_daq_rev7_sn3_0_15V_0_2026-08-11T222320Z/deimos_daq_rev7_sn3_0_15V_0_2026-08-11T222320Z_plots_dark.html>) / [Light](<deimos_daq_rev7_sn3_0_15V_0_2026-08-11T222320Z/deimos_daq_rev7_sn3_0_15V_0_2026-08-11T222320Z_plots_light.html>) |
| 0-15 V channel 1 (ain17) | `ain17` | [Dark](<deimos_daq_rev7_sn3_0_15V_1_2026-08-11T222140Z/deimos_daq_rev7_sn3_0_15V_1_2026-08-11T222140Z_plots_dark.html>) / [Light](<deimos_daq_rev7_sn3_0_15V_1_2026-08-11T222140Z/deimos_daq_rev7_sn3_0_15V_1_2026-08-11T222140Z_plots_light.html>) |
| 0-2.5 V channel 0 (ain12) | `ain12` | [Dark](<deimos_daq_rev7_sn3_0_2V5_0_2026-08-11T211346Z/deimos_daq_rev7_sn3_0_2V5_0_2026-08-11T211346Z_plots_dark.html>) / [Light](<deimos_daq_rev7_sn3_0_2V5_0_2026-08-11T211346Z/deimos_daq_rev7_sn3_0_2V5_0_2026-08-11T211346Z_plots_light.html>) |
| 0-2.5 V channel 1 (ain15) | `ain15` | [Dark](<deimos_daq_rev7_sn3_0_2V5_1_2026-08-11T211148Z/deimos_daq_rev7_sn3_0_2V5_1_2026-08-11T211148Z_plots_dark.html>) / [Light](<deimos_daq_rev7_sn3_0_2V5_1_2026-08-11T211148Z/deimos_daq_rev7_sn3_0_2V5_1_2026-08-11T211148Z_plots_light.html>) |
| 4-20 mA channel 0 (ain3) | `ain3` | [Dark](<deimos_daq_rev7_sn3_4_20_mA_0_2026-08-13T001545Z/deimos_daq_rev7_sn3_4_20_mA_0_2026-08-13T001545Z_plots_dark.html>) / [Light](<deimos_daq_rev7_sn3_4_20_mA_0_2026-08-13T001545Z/deimos_daq_rev7_sn3_4_20_mA_0_2026-08-13T001545Z_plots_light.html>) |
| 4-20 mA channel 1 (ain4) | `ain4` | [Dark](<deimos_daq_rev7_sn3_4_20_mA_1_2026-08-13T002418Z/deimos_daq_rev7_sn3_4_20_mA_1_2026-08-13T002418Z_plots_dark.html>) / [Light](<deimos_daq_rev7_sn3_4_20_mA_1_2026-08-13T002418Z/deimos_daq_rev7_sn3_4_20_mA_1_2026-08-13T002418Z_plots_light.html>) |
| 4-20 mA channel 2 (ain5) | `ain5` | [Dark](<deimos_daq_rev7_sn3_4_20_mA_2_2026-08-13T002734Z/deimos_daq_rev7_sn3_4_20_mA_2_2026-08-13T002734Z_plots_dark.html>) / [Light](<deimos_daq_rev7_sn3_4_20_mA_2_2026-08-13T002734Z/deimos_daq_rev7_sn3_4_20_mA_2_2026-08-13T002734Z_plots_light.html>) |
| 4-20 mA channel 3 (ain6) | `ain6` | [Dark](<deimos_daq_rev7_sn3_4_20_mA_3_2026-08-13T003024Z/deimos_daq_rev7_sn3_4_20_mA_3_2026-08-13T003024Z_plots_dark.html>) / [Light](<deimos_daq_rev7_sn3_4_20_mA_3_2026-08-13T003024Z/deimos_daq_rev7_sn3_4_20_mA_3_2026-08-13T003024Z_plots_light.html>) |
| RTD channel 0 (ain7) | `ain7` | [Dark](<deimos_daq_rev7_sn3_rtd_0_2026-07-31T022125Z/deimos_daq_rev7_sn3_rtd_0_2026-07-31T022125Z_plots_dark.html>) / [Light](<deimos_daq_rev7_sn3_rtd_0_2026-07-31T022125Z/deimos_daq_rev7_sn3_rtd_0_2026-07-31T022125Z_plots_light.html>) |
| RTD channel 1 (ain8) | `ain8` | [Dark](<deimos_daq_rev7_sn3_rtd_1_2026-07-31T022626Z/deimos_daq_rev7_sn3_rtd_1_2026-07-31T022626Z_plots_dark.html>) / [Light](<deimos_daq_rev7_sn3_rtd_1_2026-07-31T022626Z/deimos_daq_rev7_sn3_rtd_1_2026-07-31T022626Z_plots_light.html>) |
| RTD channel 2 (ain9) | `ain9` | [Dark](<deimos_daq_rev7_sn3_rtd_2_2026-07-31T023209Z/deimos_daq_rev7_sn3_rtd_2_2026-07-31T023209Z_plots_dark.html>) / [Light](<deimos_daq_rev7_sn3_rtd_2_2026-07-31T023209Z/deimos_daq_rev7_sn3_rtd_2_2026-07-31T023209Z_plots_light.html>) |
| Thermocouple channel 0 (ain10) | `ain10` | [Dark](<deimos_daq_rev7_sn3_tc_0_2026-08-12T215518Z/deimos_daq_rev7_sn3_tc_0_2026-08-12T215518Z_plots_dark.html>) / [Light](<deimos_daq_rev7_sn3_tc_0_2026-08-12T215518Z/deimos_daq_rev7_sn3_tc_0_2026-08-12T215518Z_plots_light.html>) |
| Thermocouple channel 1 (ain11) | `ain11` | [Dark](<deimos_daq_rev7_sn3_tc_1_2026-08-12T215816Z/deimos_daq_rev7_sn3_tc_1_2026-08-12T215816Z_plots_dark.html>) / [Light](<deimos_daq_rev7_sn3_tc_1_2026-08-12T215816Z/deimos_daq_rev7_sn3_tc_1_2026-08-12T215816Z_plots_light.html>) |
| x26 voltage channel 0 (ain18) | `ain18` | [Dark](<deimos_daq_rev7_sn3_x26_0_2026-08-12T031812Z/deimos_daq_rev7_sn3_x26_0_2026-08-12T031812Z_plots_dark.html>) / [Light](<deimos_daq_rev7_sn3_x26_0_2026-08-12T031812Z/deimos_daq_rev7_sn3_x26_0_2026-08-12T031812Z_plots_light.html>) |
| x26 voltage channel 1 (ain19) | `ain19` | [Dark](<deimos_daq_rev7_sn3_x26_1_2026-08-12T032042Z/deimos_daq_rev7_sn3_x26_1_2026-08-12T032042Z_plots_dark.html>) / [Light](<deimos_daq_rev7_sn3_x26_1_2026-08-12T032042Z/deimos_daq_rev7_sn3_x26_1_2026-08-12T032042Z_plots_light.html>) |

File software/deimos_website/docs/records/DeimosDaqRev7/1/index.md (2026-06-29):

# DeimosDaqRev7 SN 1 Records

## Calibration Record

- [Calibration JSON](<cal.json>)

## Calibration Reports

| Instrument | Channel | Report |
| --- | --- | --- |
| 0-15 V channel 0 (ain16) | `ain16` | [Dark](<deimos_daq_rev7_sn1_0_15V_0_2026-06-25T014626Z/deimos_daq_rev7_sn1_0_15V_0_2026-06-25T014626Z_plots_dark.html>) / [Light](<deimos_daq_rev7_sn1_0_15V_0_2026-06-25T014626Z/deimos_daq_rev7_sn1_0_15V_0_2026-06-25T014626Z_plots_light.html>) |
| 0-15 V channel 1 (ain17) | `ain17` | [Dark](<deimos_daq_rev7_sn1_0_15V_1_2026-06-25T015017Z/deimos_daq_rev7_sn1_0_15V_1_2026-06-25T015017Z_plots_dark.html>) / [Light](<deimos_daq_rev7_sn1_0_15V_1_2026-06-25T015017Z/deimos_daq_rev7_sn1_0_15V_1_2026-06-25T015017Z_plots_light.html>) |
| 0-2.5 V channel 0 (ain12) | `ain12` | [Dark](<deimos_daq_rev7_sn1_0_2V5_0_2026-06-25T014005Z/deimos_daq_rev7_sn1_0_2V5_0_2026-06-25T014005Z_plots_dark.html>) / [Light](<deimos_daq_rev7_sn1_0_2V5_0_2026-06-25T014005Z/deimos_daq_rev7_sn1_0_2V5_0_2026-06-25T014005Z_plots_light.html>) |
| 0-2.5 V channel 1 (ain15) | `ain15` | [Dark](<deimos_daq_rev7_sn1_0_2V5_1_2026-06-25T014251Z/deimos_daq_rev7_sn1_0_2V5_1_2026-06-25T014251Z_plots_dark.html>) / [Light](<deimos_daq_rev7_sn1_0_2V5_1_2026-06-25T014251Z/deimos_daq_rev7_sn1_0_2V5_1_2026-06-25T014251Z_plots_light.html>) |
| 4-20 mA channel 0 (ain3) | `ain3` | [Dark](<deimos_daq_rev7_sn1_4_20_mA_0_2026-06-25T002526Z/deimos_daq_rev7_sn1_4_20_mA_0_2026-06-25T002526Z_plots_dark.html>) / [Light](<deimos_daq_rev7_sn1_4_20_mA_0_2026-06-25T002526Z/deimos_daq_rev7_sn1_4_20_mA_0_2026-06-25T002526Z_plots_light.html>) |
| 4-20 mA channel 1 (ain4) | `ain4` | [Dark](<deimos_daq_rev7_sn1_4_20_mA_1_2026-06-25T002705Z/deimos_daq_rev7_sn1_4_20_mA_1_2026-06-25T002705Z_plots_dark.html>) / [Light](<deimos_daq_rev7_sn1_4_20_mA_1_2026-06-25T002705Z/deimos_daq_rev7_sn1_4_20_mA_1_2026-06-25T002705Z_plots_light.html>) |
| 4-20 mA channel 2 (ain5) | `ain5` | [Dark](<deimos_daq_rev7_sn1_4_20_mA_2_2026-06-25T002833Z/deimos_daq_rev7_sn1_4_20_mA_2_2026-06-25T002833Z_plots_dark.html>) / [Light](<deimos_daq_rev7_sn1_4_20_mA_2_2026-06-25T002833Z/deimos_daq_rev7_sn1_4_20_mA_2_2026-06-25T002833Z_plots_light.html>) |
| 4-20 mA channel 3 (ain6) | `ain6` | [Dark](<deimos_daq_rev7_sn1_4_20_mA_3_2026-06-25T003022Z/deimos_daq_rev7_sn1_4_20_mA_3_2026-06-25T003022Z_plots_dark.html>) / [Light](<deimos_daq_rev7_sn1_4_20_mA_3_2026-06-25T003022Z/deimos_daq_rev7_sn1_4_20_mA_3_2026-06-25T003022Z_plots_light.html>) |
| RTD channel 0 (ain7) | `ain7` | [Dark](<deimos_daq_rev7_sn1_rtd_0_2026-06-25T003331Z/deimos_daq_rev7_sn1_rtd_0_2026-06-25T003331Z_plots_dark.html>) / [Light](<deimos_daq_rev7_sn1_rtd_0_2026-06-25T003331Z/deimos_daq_rev7_sn1_rtd_0_2026-06-25T003331Z_plots_light.html>) |
| RTD channel 1 (ain8) | `ain8` | [Dark](<deimos_daq_rev7_sn1_rtd_1_2026-06-25T004102Z/deimos_daq_rev7_sn1_rtd_1_2026-06-25T004102Z_plots_dark.html>) / [Light](<deimos_daq_rev7_sn1_rtd_1_2026-06-25T004102Z/deimos_daq_rev7_sn1_rtd_1_2026-06-25T004102Z_plots_light.html>) |
| RTD channel 2 (ain9) | `ain9` | [Dark](<deimos_daq_rev7_sn1_rtd_2_2026-06-25T004447Z/deimos_daq_rev7_sn1_rtd_2_2026-06-25T004447Z_plots_dark.html>) / [Light](<deimos_daq_rev7_sn1_rtd_2_2026-06-25T004447Z/deimos_daq_rev7_sn1_rtd_2_2026-06-25T004447Z_plots_light.html>) |
| Thermocouple channel 0 (ain10) | `ain10` | [Dark](<deimos_daq_rev7_sn1_tc_0_2026-06-25T004848Z/deimos_daq_rev7_sn1_tc_0_2026-06-25T004848Z_plots_dark.html>) / [Light](<deimos_daq_rev7_sn1_tc_0_2026-06-25T004848Z/deimos_daq_rev7_sn1_tc_0_2026-06-25T004848Z_plots_light.html>) |
| Thermocouple channel 1 (ain11) | `ain11` | [Dark](<deimos_daq_rev7_sn1_tc_1_2026-06-25T005335Z/deimos_daq_rev7_sn1_tc_1_2026-06-25T005335Z_plots_dark.html>) / [Light](<deimos_daq_rev7_sn1_tc_1_2026-06-25T005335Z/deimos_daq_rev7_sn1_tc_1_2026-06-25T005335Z_plots_light.html>) |
| x26 voltage channel 0 (ain18) | `ain18` | [Dark](<deimos_daq_rev7_sn1_x26_0_2026-06-25T015331Z/deimos_daq_rev7_sn1_x26_0_2026-06-25T015331Z_plots_dark.html>) / [Light](<deimos_daq_rev7_sn1_x26_0_2026-06-25T015331Z/deimos_daq_rev7_sn1_x26_0_2026-06-25T015331Z_plots_light.html>) |
| x26 voltage channel 1 (ain19) | `ain19` | [Dark](<deimos_daq_rev7_sn1_x26_1_2026-06-25T015651Z/deimos_daq_rev7_sn1_x26_1_2026-06-25T015651Z_plots_dark.html>) / [Light](<deimos_daq_rev7_sn1_x26_1_2026-06-25T015651Z/deimos_daq_rev7_sn1_x26_1_2026-06-25T015651Z_plots_light.html>) |

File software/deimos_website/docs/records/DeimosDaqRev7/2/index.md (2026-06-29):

# DeimosDaqRev7 SN 2 Records

## Calibration Record

- [Calibration JSON](<cal.json>)

## Calibration Reports

| Instrument | Channel | Report |
| --- | --- | --- |
| 0-15 V channel 0 (ain16) | `ain16` | [Dark](<deimos_daq_rev7_sn2_0_15V_0_2026-06-21T233755Z/deimos_daq_rev7_sn2_0_15V_0_2026-06-21T233755Z_plots_dark.html>) / [Light](<deimos_daq_rev7_sn2_0_15V_0_2026-06-21T233755Z/deimos_daq_rev7_sn2_0_15V_0_2026-06-21T233755Z_plots_light.html>) |
| 0-15 V channel 1 (ain17) | `ain17` | [Dark](<deimos_daq_rev7_sn2_0_15V_1_2026-06-21T234003Z/deimos_daq_rev7_sn2_0_15V_1_2026-06-21T234003Z_plots_dark.html>) / [Light](<deimos_daq_rev7_sn2_0_15V_1_2026-06-21T234003Z/deimos_daq_rev7_sn2_0_15V_1_2026-06-21T234003Z_plots_light.html>) |
| 0-2.5 V channel 0 (ain12) | `ain12` | [Dark](<deimos_daq_rev7_sn2_0_2V5_0_2026-06-21T233309Z/deimos_daq_rev7_sn2_0_2V5_0_2026-06-21T233309Z_plots_dark.html>) / [Light](<deimos_daq_rev7_sn2_0_2V5_0_2026-06-21T233309Z/deimos_daq_rev7_sn2_0_2V5_0_2026-06-21T233309Z_plots_light.html>) |
| 0-2.5 V channel 1 (ain15) | `ain15` | [Dark](<deimos_daq_rev7_sn2_0_2V5_1_2026-06-21T233535Z/deimos_daq_rev7_sn2_0_2V5_1_2026-06-21T233535Z_plots_dark.html>) / [Light](<deimos_daq_rev7_sn2_0_2V5_1_2026-06-21T233535Z/deimos_daq_rev7_sn2_0_2V5_1_2026-06-21T233535Z_plots_light.html>) |
| 4-20 mA channel 0 (ain3) | `ain3` | [Dark](<deimos_daq_rev7_sn2_4_20_mA_0_2026-06-21T235044Z/deimos_daq_rev7_sn2_4_20_mA_0_2026-06-21T235044Z_plots_dark.html>) / [Light](<deimos_daq_rev7_sn2_4_20_mA_0_2026-06-21T235044Z/deimos_daq_rev7_sn2_4_20_mA_0_2026-06-21T235044Z_plots_light.html>) |
| 4-20 mA channel 1 (ain4) | `ain4` | [Dark](<deimos_daq_rev7_sn2_4_20_mA_1_2026-06-21T235257Z/deimos_daq_rev7_sn2_4_20_mA_1_2026-06-21T235257Z_plots_dark.html>) / [Light](<deimos_daq_rev7_sn2_4_20_mA_1_2026-06-21T235257Z/deimos_daq_rev7_sn2_4_20_mA_1_2026-06-21T235257Z_plots_light.html>) |
| 4-20 mA channel 2 (ain5) | `ain5` | [Dark](<deimos_daq_rev7_sn2_4_20_mA_2_2026-06-21T235421Z/deimos_daq_rev7_sn2_4_20_mA_2_2026-06-21T235421Z_plots_dark.html>) / [Light](<deimos_daq_rev7_sn2_4_20_mA_2_2026-06-21T235421Z/deimos_daq_rev7_sn2_4_20_mA_2_2026-06-21T235421Z_plots_light.html>) |
| 4-20 mA channel 3 (ain6) | `ain6` | [Dark](<deimos_daq_rev7_sn2_4_20_mA_3_2026-06-21T235526Z/deimos_daq_rev7_sn2_4_20_mA_3_2026-06-21T235526Z_plots_dark.html>) / [Light](<deimos_daq_rev7_sn2_4_20_mA_3_2026-06-21T235526Z/deimos_daq_rev7_sn2_4_20_mA_3_2026-06-21T235526Z_plots_light.html>) |
| RTD channel 0 (ain7) | `ain7` | [Dark](<deimos_daq_rev7_sn2_rtd_0_2026-06-21T231140Z/deimos_daq_rev7_sn2_rtd_0_2026-06-21T231140Z_plots_dark.html>) / [Light](<deimos_daq_rev7_sn2_rtd_0_2026-06-21T231140Z/deimos_daq_rev7_sn2_rtd_0_2026-06-21T231140Z_plots_light.html>) |
| RTD channel 1 (ain8) | `ain8` | [Dark](<deimos_daq_rev7_sn2_rtd_1_2026-06-21T231455Z/deimos_daq_rev7_sn2_rtd_1_2026-06-21T231455Z_plots_dark.html>) / [Light](<deimos_daq_rev7_sn2_rtd_1_2026-06-21T231455Z/deimos_daq_rev7_sn2_rtd_1_2026-06-21T231455Z_plots_light.html>) |
| RTD channel 2 (ain9) | `ain9` | [Dark](<deimos_daq_rev7_sn2_rtd_2_2026-06-21T231757Z/deimos_daq_rev7_sn2_rtd_2_2026-06-21T231757Z_plots_dark.html>) / [Light](<deimos_daq_rev7_sn2_rtd_2_2026-06-21T231757Z/deimos_daq_rev7_sn2_rtd_2_2026-06-21T231757Z_plots_light.html>) |
| Thermocouple channel 0 (ain10) | `ain10` | [Dark](<deimos_daq_rev7_sn2_tc_0_2026-06-21T232116Z/deimos_daq_rev7_sn2_tc_0_2026-06-21T232116Z_plots_dark.html>) / [Light](<deimos_daq_rev7_sn2_tc_0_2026-06-21T232116Z/deimos_daq_rev7_sn2_tc_0_2026-06-21T232116Z_plots_light.html>) |
| Thermocouple channel 1 (ain11) | `ain11` | [Dark](<deimos_daq_rev7_sn2_tc_1_2026-06-21T232755Z/deimos_daq_rev7_sn2_tc_1_2026-06-21T232755Z_plots_dark.html>) / [Light](<deimos_daq_rev7_sn2_tc_1_2026-06-21T232755Z/deimos_daq_rev7_sn2_tc_1_2026-06-21T232755Z_plots_light.html>) |
| x26 voltage channel 0 (ain18) | `ain18` | [Dark](<deimos_daq_rev7_sn2_x26_0_2026-06-21T234218Z/deimos_daq_rev7_sn2_x26_0_2026-06-21T234218Z_plots_dark.html>) / [Light](<deimos_daq_rev7_sn2_x26_0_2026-06-21T234218Z/deimos_daq_rev7_sn2_x26_0_2026-06-21T234218Z_plots_light.html>) |
| x26 voltage channel 1 (ain19) | `ain19` | [Dark](<deimos_daq_rev7_sn2_x26_1_2026-06-21T234515Z/deimos_daq_rev7_sn2_x26_1_2026-06-21T234515Z_plots_dark.html>) / [Light](<deimos_daq_rev7_sn2_x26_1_2026-06-21T234515Z/deimos_daq_rev7_sn2_x26_1_2026-06-21T234515Z_plots_light.html>) |

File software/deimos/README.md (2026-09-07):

# Deimos

Control program and data integrations for the Deimos data acquisition ecosystem.

Library usage examples are in [examples](examples). Hardware calibration,
validation, and benchmark tools are in [deimos_procedures](../deimos_procedures).

See the [project readme](https://github.com/deimoscontrols/deimos/blob/main/README.md) for contact details as well as commentary about
the goals and state of the project.

The control program and the firmware-software shared library share a
[changelog](https://github.com/deimoscontrols/deimos/blob/main/CHANGELOG.md) at the workspace level.

Deimos DAQ hardware

### Install - Rust

```bash
cargo add deimos
```

### Install - Python

```bash
pip install deimos-daq
```

## Features & Roadmap

✅ Implemented | 💡 Planned

| Feature Category | Features |
|---|---|
| Control Loop | ✅ Fixed-dt roundtrip control loop<br>✅ Network scanning for available hardware<br>✅ Planned loop termination<br>✅ Global event logging<br>✅ Reconnection<br>✅ Low-CPU-usage background operation|
| Control Calcs | ✅ User-defined custom calcs<br>✅ Explicit (acyclic) calc expression<br>✅ Low-pass filters<br>✅ Sequenced state machines<br>✅ Polynomial calibration curves<br>💡 Cyclic expressions with explicit time-delay<br>💡 Prototype calc w/ rhai script-defined inner function |
| Data Integrations| ✅ User-defined custom targets<br>✅ Manual read/write<br>✅ CSV<br>✅ In-memory dataframe<br>✅ TimescaleDB<br>💡 InfluxDB<br>💡 Zarr file/bucket<br>💡 Generic sqlite, postgres, etc.|
| Hardware Peripherals| ✅ Deimos DAQs<br>✅ User-defined custom hardware<br>✅ User-defined hardware drivers<br>✅ Hardware-out-of-the-loop wrapper|
| Socket Interfaces<br>(peripheral I/O)| ✅ User-defined custom interfaces<br>✅ UDP/IPV4<br>✅ Unix socket<br>✅ Thread channel |

## Concept of Operation

The control program follows the hardware peripheral state machine,
which is linear except that an error in any peripheral state results
in returning to `Connecting`.

Peripheral states:

1. `Connecting` (no communication with the control machine)
2. `Binding` (waiting to associate with a control machine)
3. `Configuring` (waiting for operation-specific configuration from control machine)
4. `Operating` (roundtrip control)

The controller initialization schedule is:

```text
                  --------------------binding timeout windows
                 /                          /
                /    Controller init       /           
             |====|=====================|====|         timeout to operating
     scan for|                          |==============|
  peripherals|                          |      \
   (broadcast|              sent binding|       \
     binding)|                          |    configuring window
                             peripherals|
                              transition|
                          to configuring|            
```

In words,

1. Scan network for peripherals available to bind
    * Broadcast binding request, but do not send configuration; allow Configuring to time out back to Connecting
2. Initialize controller (set up data integrations, initialize internal state, etc)
3. Send binding request
4. Wait for binding responses
5. Send configuration
6. Wait for start of Operating

Peripherals acknowledge binding and transition to configuring on their next internal cycle (usually 1ms) after receiving a request to bind. They will then wait for configuration input until the timeout
to operating, and either proceed to `Operating` if configuration was
successful, or return to `Connecting` (and likely return immediately to `Binding`) if configuration was not successful.

The control loop then follows a fixed schedule on each cycle:

1. Send control input to peripherals
2. Wait for outputs from peripherals
    * Target synchronization to middle of cycle
3. Update time-sync control
4. Run calculations on peripheral outputs

Control loop timing uses the control machine's best available monotonic clock. Both system time in UTC with nanoseconds and monotonic clock time
are stored in order to support post-processing adjustments to
account for the slow drift of the monotonic clock relative to system time.

## Example: 200Hz Control Program w/ 2 DAQs

```rust
use std::time::Duration;

use deimos::calc::{Constant, Sin};
use deimos::peripheral::{PluginMap, analog_i_rev_3::AnalogIRev3};
use controller::context::ControllerCtx;
use deimos::*;

// The name of the operation will be used as the table name for databases,
// or as the file name for local storage.
let op_name = "test_op".to_owned();

// An optional dictionary mapping user-defined custom hardware
// peripheral model numbers to initializer functions.
let peripheral_plugins: Option<PluginMap> = None;

// Configure the controller
//    Sample interval is taken as integer nanoseconds
//    so that any rounding and loss of precision is visible to the user
let rate_hz = 200.0;
let dt_ns = (1e9_f64 / rate_hz).ceil() as u32;  // Control cycle period

// Define idle controller
let mut ctx = ControllerCtx::default();
ctx.op_name = op_name;
ctx.dt_ns = dt_ns;
let mut controller = Controller::new(ctx);

// Set up any number of data integrations,
// all of which will receive the same data at each cycle of the control loop
//    TSDB-flavored postgres database
let buffer_window = Duration::from_nanos(1); // Non-buffering mode
let retention_time = Duration::from_secs(60 * 60);
let timescale_dispatcher: Box<dyn Dispatcher> = TimescaleDbDispatcher::new(
    "<database name>",  // Database name
    "<database address>", // URL or unix socket interface
    "<username>",  // Login name; for unix socket, must match OS username
    "<token env var>",  // Environment variable containing password or token
    buffer_window,
    retention_time,
);
controller.add_dispatcher("tsdb", timescale_dispatcher);

//    A 50MB CSV file that will be wrapped and overwritten when full
let csv_dispatcher: Box<dyn Dispatcher> =
    CsvDispatcher::new(50, dispatcher::Overflow::Wrap);
controller.add_dispatcher("csv", csv_dispatcher);

// Associate hardware peripherals that we expect to find on the network
// The controller can also run with no peripherals at all, and simply do
// calculations on a fixed time interval.
controller.add_peripheral("p1", Box::new(AnalogIRev3 { serial_number: 1 }));
controller.add_peripheral("p2", Box::new(AnalogIRev3 { serial_number: 2 }));

// Set up calcs that will be run at each cycle
//     Add a constant for duty cycle and a sine wave for frequency
let freq = Sin::new(1.0 / (rate_hz / 100.0), 0.25, 100.0, 250_000.0);
let duty = Constant::new(0.5);
controller.add_calc("freq", freq);
controller.add_calc("duty", duty);
//     Set a PWM on the first peripheral to change its frequency in time
controller.set_peripheral_input_source("p1.pwm0_freq", "freq.y");  // A value to be written to the hardware
controller.set_peripheral_input_source("p1.pwm0_duty", "duty.y");
//     Set a PWM frequency on one peripheral based on a measured temperature from the other peripheral
controller.set_peripheral_input_source("p2.pwm0_duty", "duty.y");  // Values can be referenced any number of times
controller.set_peripheral_input_source("p2.pwm0_freq", "p1_rtd_5.temperature_K");

// Serialize and deserialize the controller (for demonstration purposes).
// All of the configuration up to this point, including any custom peripheral plugins
// or user-defined calcs, are serialized with the controller and can be written to and read from a json file.
let serialized_controller: String = serde_json::to_string_pretty(&controller).unwrap();
let _deserialized_controller: Controller = serde_json::from_str(&serialized_controller).unwrap();

// Run the control program
// (skipped here because there are no peripherals
// or databases on the network in the test environment).
// controller.run(&peripheral_plugins, None);
```

## Direct-to-PC Ethernet Connection and Statically-Addressed Networks

Deimos DAQs can be connected directly to your computer by ethernet, bypassing the need
for a router or network switch. They can also be used on networks with a switch but no router.

When a Deimos DAQ connects to a network without a DHCP server to provide dynamic IP address assignments,
it will automatically self-assign an IP address in the `169.254.x.[2-254]/16` range.
It will attempt up to 3 candidate addresses, which limits the maximum amount of address resolution spam on the network, while also yielding a trivially small probability that no candidate address is available.

The rev7 firmware's IPv4 address manager follows this state machine:

```mermaid
stateDiagram-v2
    direction LR

    classDef a stroke-width:2px

    [*] --> Unconfigured:::a

    Unconfigured --> TentativeFallback:::a : Claim next MAC-derived<br>static address candidate
    Unconfigured --> ActiveDhcp:::a : DHCP configured

    TentativeFallback --> ActiveFallback:::a : No ARP conflict
    TentativeFallback --> Unconfigured:::a : ARP conflict
    TentativeFallback --> ActiveDhcp:::a : DHCP configured

    ActiveFallback --> ActiveDhcp:::a : DHCP configured

    ActiveDhcp:::a --> Unconfigured: DHCP deconfigured
```

To connect directly without a router,
1. Connect the DAQ's ethernet cable to your computer's ethernet port.
  * (or to a shared network switch with no router).
  * If your computer does not have an ethernet port, an ethernet-to-USB adapter can be used at the expense of added latency.
2. Check your computer's network settings.
  * Make sure that a static IP address was assigned in the 169.254.X.Y range.
  * This should occur automatically on MacOS and Windows.
  * On linux, you may need to manually set a static IPV4 address: `169.254.254.1/16`

Make sure the netmask for your computer's static address is set to exactly `/16 (255.255.0.0)`.

Otherwise, the DAQ will not recognize your computer as being on the same link-local network, and will not respond to your attempts to scan or bind it.

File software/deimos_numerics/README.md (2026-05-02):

# deimos_numerics

Numerical methods and control systems analysis.

## Feature Status

| Feature area | Sparse | Dense | Continuous | Discrete | no-std | no-alloc | wasm |
| --- | --- | --- | --- | --- | --- | --- | --- |
| Linear solves | ✅ | ✅ | n/a | n/a | ✅ | n/a | ✅ |
| Matrix decompositions | 💡 | ✅ | n/a | n/a | ✅ | n/a | ✅ |
| Matrix equations | n/a | ✅ | ✅ | ✅ | ✅ | n/a | ✅ |
| LTI models and analysis | n/a | ✅ | ✅ | ✅ | ✅ | n/a | ✅ |
| Filter design | n/a | ✅ | ✅ | ✅ | ✅ | n/a | ✅ |
| Control synthesis | n/a | ✅ | ✅ | ✅ | ✅ | n/a | ✅ |
| Estimation | n/a | ✅ | n/a | ✅ | ✅ | n/a | ✅ |
| Embedded fixed runtime | n/a | ✅ | n/a | ✅ | ✅ | ✅ | ✅ |
| Identification and realization | n/a | ✅ | n/a | ✅ | ✅ | n/a | ✅ |
| Model reduction | n/a | ✅ | ✅ | 💡 | ✅ | n/a | ✅ |

## Numerical Methods

### Linear solves

| Feature | Sparse | Dense | Continuous | Discrete | no-std | no-alloc | wasm |
| --- | --- | --- | --- | --- | --- | --- | --- |
| LU factorization | ✅ | ✅ | n/a | n/a | ✅ | n/a | ✅ |
| Iterative refinement | ✅ | n/a | n/a | n/a | ✅ | n/a | ✅ |
| Cholesky / LDLT | ✅ | ✅ | n/a | n/a | ✅ | n/a | ✅ |
| BiCGSTAB | ✅ | n/a | n/a | n/a | ✅ | n/a | ✅ |
| Equilibration | ✅ | 💡 | n/a | n/a | ✅ | n/a | ✅ |
| Preconditioners | ✅ | n/a | n/a | n/a | ✅ | n/a | ✅ |
| Schur-complement operators | ✅ | n/a | n/a | n/a | ✅ | n/a | ✅ |

### Matrix decompositions

| Feature | Sparse | Dense | Continuous | Discrete | no-std | no-alloc | wasm |
| --- | --- | --- | --- | --- | --- | --- | --- |
| Eigenvalues and eigenvectors | ✅ | ✅ | n/a | n/a | ✅ | n/a | ✅ |
| Self-adjoint eigen decomposition | ✅ | ✅ | n/a | n/a | ✅ | n/a | ✅ |
| Generalized eigen decomposition | 💡 | ✅ | n/a | n/a | ✅ | n/a | ✅ |
| Singular value decomposition | ✅ | ✅ | n/a | n/a | ✅ | n/a | ✅ |
| Matrix-free operator adapters | ✅ | n/a | n/a | n/a | ✅ | n/a | ✅ |
| Convergence diagnostics | ✅ | ✅ | n/a | n/a | ✅ | n/a | ✅ |

## Control Systems & Digital Signal Processing

### Embedded fixed runtime

| Feature | Sparse | Dense | Continuous | Discrete | no-std | no-alloc | wasm |
| --- | --- | --- | --- | --- | --- | --- | --- |
| Fixed-size matrix / vector storage | n/a | ✅ | n/a | ✅ | ✅ | ✅ | ✅ |
| Fixed discrete state-space runtime | n/a | ✅ | n/a | ✅ | ✅ | ✅ | ✅ |
| Fixed FIR runtime | n/a | ✅ | n/a | ✅ | ✅ | ✅ | ✅ |
| Fixed delta-SOS runtime | n/a | ✅ | n/a | ✅ | ✅ | ✅ | ✅ |
| Fixed PID runtime | n/a | ✅ | n/a | ✅ | ✅ | ✅ | ✅ |
| Fractional-delay FIR taps | n/a | ✅ | n/a | ✅ | ✅ | ✅ | ✅ |
| Fixed discrete Kalman filter | n/a | ✅ | n/a | ✅ | ✅ | ✅ | ✅ |
| Fixed steady-state Kalman filter | n/a | ✅ | n/a | ✅ | ✅ | ✅ | ✅ |

### Matrix equations

| Feature | Sparse | Dense | Continuous | Discrete | no-std | no-alloc | wasm |
| --- | --- | --- | --- | --- | --- | --- | --- |
| Lyapunov solve | ✅ | ✅ | ✅ | n/a | ✅ | n/a | ✅ |
| Stein solve | ✅ | ✅ | n/a | ✅ | ✅ | n/a | ✅ |
| Controllability Gramians | ✅ | ✅ | ✅ | ✅ | ✅ | n/a | ✅ |
| Observability Gramians | ✅ | ✅ | ✅ | ✅ | ✅ | n/a | ✅ |
| Algebraic Riccati equations | 💡 | ✅ | ✅ | ✅ | ✅ | n/a | ✅ |

### LTI models and analysis

| Feature | Sparse | Dense | Continuous | Discrete | no-std | no-alloc | wasm |
| --- | --- | --- | --- | --- | --- | --- | --- |
| State-space models | ✅ | ✅ | ✅ | ✅ | ✅ | n/a | ✅ |
| Transfer functions | n/a | ✅ | ✅ | ✅ | ✅ | n/a | ✅ |
| Zero-pole-gain models | n/a | ✅ | ✅ | ✅ | ✅ | n/a | ✅ |
| Second-order sections | n/a | ✅ | ✅ | ✅ | ✅ | n/a | ✅ |
| FIR models | n/a | ✅ | n/a | ✅ | ✅ | n/a | ✅ |
| Pole and stability analysis | ✅ | ✅ | ✅ | ✅ | ✅ | n/a | ✅ |
| Frequency-response data | ✅ | ✅ | ✅ | ✅ | ✅ | n/a | ✅ |
| Step, impulse, and simulation data | 💡 | ✅ | ✅ | ✅ | ✅ | n/a | ✅ |
| Loop margins / Nyquist / Nichols | n/a | ✅ | ✅ | ✅ | ✅ | n/a | ✅ |
| Root locus | n/a | ✅ | ✅ | ✅ | ✅ | n/a | ✅ |
| Explicit process models | n/a | ✅ | ✅ | 💡 | ✅ | n/a | ✅ |

### Filter design

| Feature | Sparse | Dense | Continuous | Discrete | no-std | no-alloc | wasm |
| --- | --- | --- | --- | --- | --- | --- | --- |
| Butterworth IIR design | n/a | ✅ | ✅ | ✅ | ✅ | n/a | ✅ |
| Chebyshev I IIR design | n/a | ✅ | ✅ | ✅ | ✅ | n/a | ✅ |
| Bessel IIR design | n/a | ✅ | ✅ | n/a | ✅ | n/a | ✅ |
| Lowpass / highpass transforms | n/a | ✅ | ✅ | ✅ | ✅ | n/a | ✅ |
| Bandpass / bandstop transforms | n/a | ✅ | ✅ | ✅ | ✅ | n/a | ✅ |
| Minimum-order selection | n/a | ✅ | ✅ | ✅ | ✅ | n/a | ✅ |
| SOS output | n/a | ✅ | ✅ | ✅ | ✅ | n/a | ✅ |
| Transfer-function output | n/a | ✅ | ✅ | ✅ | ✅ | n/a | ✅ |
| Savitzky-Golay FIR design | n/a | ✅ | n/a | ✅ | ✅ | n/a | ✅ |
| Delta-SOS runtime form | n/a | ✅ | n/a | ✅ | ✅ | n/a | ✅ |

### Control synthesis

| Feature | Sparse | Dense | Continuous | Discrete | no-std | no-alloc | wasm |
| --- | --- | --- | --- | --- | --- | --- | --- |
| LQR / DLQR | n/a | ✅ | ✅ | ✅ | ✅ | n/a | ✅ |
| LQG / DLQG | n/a | ✅ | ✅ | ✅ | ✅ | n/a | ✅ |
| Pole placement | n/a | ✅ | ✅ | ✅ | ✅ | n/a | ✅ |
| PID runtime | n/a | ✅ | n/a | ✅ | ✅ | n/a | ✅ |
| Frequency-domain PID design | n/a | ✅ | ✅ | ✅ | ✅ | n/a | ✅ |
| Process-model PID design | n/a | ✅ | ✅ | n/a | ✅ | n/a | ✅ |
| Step-response PID design | n/a | ✅ | n/a | ✅ | ✅ | n/a | ✅ |
| OKID / ERA PID design | n/a | ✅ | n/a | ✅ | ✅ | n/a | ✅ |

### Estimation

| Feature | Sparse | Dense | Continuous | Discrete | no-std | no-alloc | wasm |
| --- | --- | --- | --- | --- | --- | --- | --- |
| LQE / DLQE design | n/a | ✅ | ✅ | ✅ | ✅ | n/a | ✅ |
| Fixed-gain observer runtime | n/a | ✅ | ✅ | ✅ | ✅ | n/a | ✅ |
| Time-varying Kalman filter | n/a | ✅ | n/a | ✅ | ✅ | n/a | ✅ |
| Steady-state Kalman filter | n/a | ✅ | n/a | ✅ | ✅ | n/a | ✅ |
| EKF runtime | n/a | ✅ | n/a | ✅ | ✅ | n/a | ✅ |
| UKF runtime | n/a | ✅ | n/a | ✅ | ✅ | n/a | ✅ |

### Identification and realization

| Feature | Sparse | Dense | Continuous | Discrete | no-std | no-alloc | wasm |
| --- | --- | --- | --- | --- | --- | --- | --- |
| Markov sequences | n/a | ✅ | n/a | ✅ | ✅ | n/a | ✅ |
| Block-Hankel assembly | n/a | ✅ | n/a | ✅ | ✅ | n/a | ✅ |
| Shifted Hankel pairs | n/a | ✅ | n/a | ✅ | ✅ | n/a | ✅ |
| ERA from Markov data | n/a | ✅ | n/a | ✅ | ✅ | n/a | ✅ |
| ERA from shifted Hankel data | n/a | ✅ | n/a | ✅ | ✅ | n/a | ✅ |
| OKID from sampled I/O data | n/a | ✅ | n/a | ✅ | ✅ | n/a | ✅ |

### Model reduction

| Feature | Sparse | Dense | Continuous | Discrete | no-std | no-alloc | wasm |
| --- | --- | --- | --- | --- | --- | --- | --- |
| HSVD from dense Gramians | n/a | ✅ | ✅ | ✅ | ✅ | n/a | ✅ |
| HSVD from low-rank factors | ✅ | ✅ | ✅ | ✅ | ✅ | n/a | ✅ |
| Balanced realization | n/a | ✅ | ✅ | ✅ | ✅ | n/a | ✅ |
| Balanced truncation | ✅ | ✅ | ✅ | ✅ | ✅ | n/a | ✅ |
| Reduced-order diagnostics | ✅ | ✅ | ✅ | ✅ | ✅ | n/a | ✅ |

## License

Licensed under either of

* Apache License, Version 2.0, ([LICENSE-APACHE](LICENSE-APACHE) or <http://www.apache.org/licenses/LICENSE-2.0>)
* MIT license ([LICENSE-MIT](LICENSE-MIT) or <http://opensource.org/licenses/MIT>)

at your option.

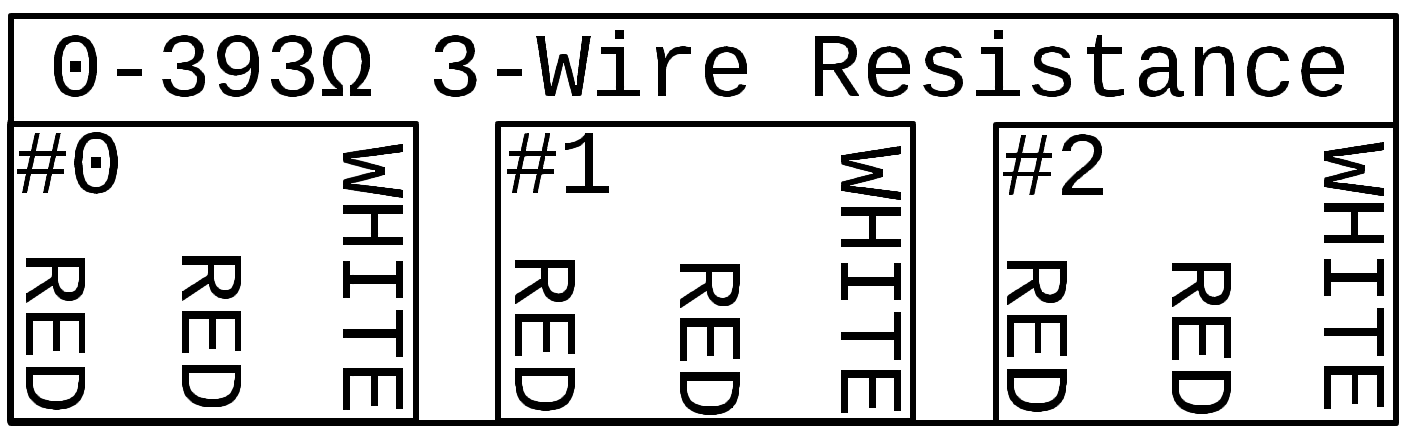
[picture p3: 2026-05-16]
hardware/boards/deimos_daq_rev8/enclosure/labels/res.png

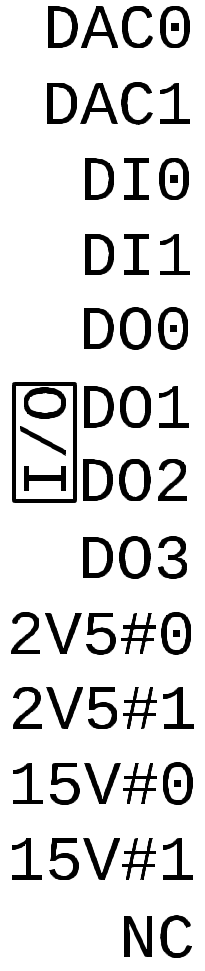
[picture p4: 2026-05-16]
hardware/boards/deimos_daq_rev8/enclosure/labels/breakout.png

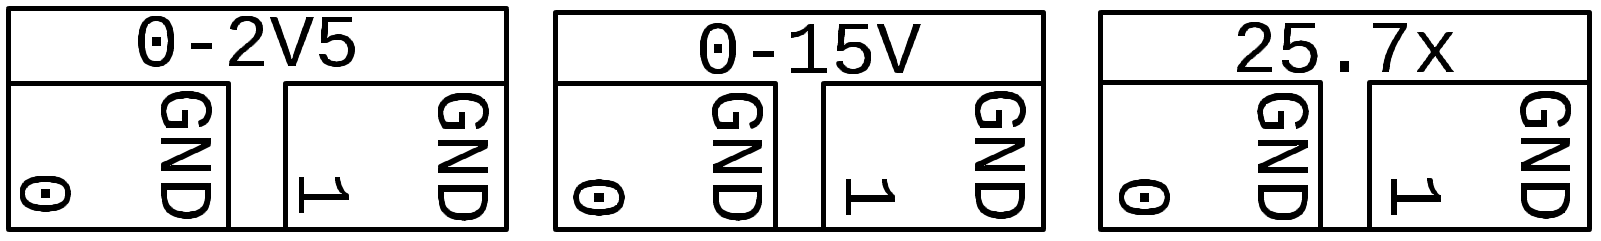
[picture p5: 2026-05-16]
hardware/boards/deimos_daq_rev8/enclosure/labels/voltage.png

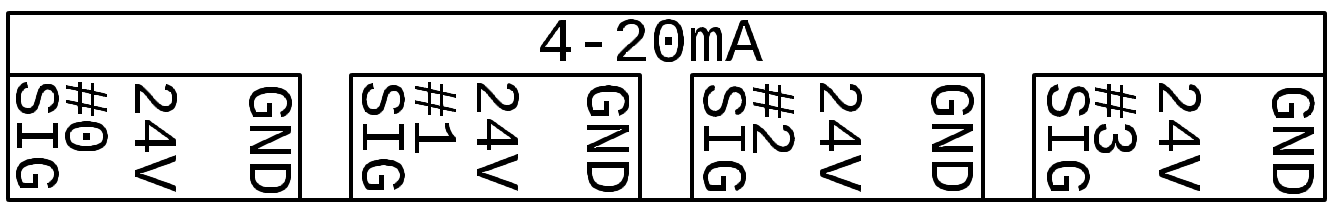
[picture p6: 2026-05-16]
hardware/boards/deimos_daq_rev8/enclosure/labels/4-20mA.png

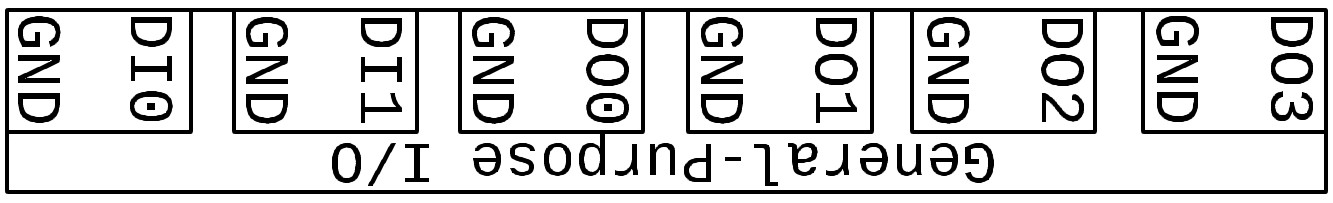
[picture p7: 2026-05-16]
hardware/boards/deimos_daq_rev8/enclosure/labels/gpio.png

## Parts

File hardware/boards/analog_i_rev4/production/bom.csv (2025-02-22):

Designator | Footprint | Quantity | Value | LCSC Part #
C10001, C10005, C11004, C11009, C12001, C12006 | 0603 | 6 | 0.1uF 50V 0603 | C14663
C10002, C10003, C10004, C11005, C11006, C11011, C12002, C12003, C12008, C17008, C20001, C24001, C28001, C32001, C8003 | 0805 | 15 | 10uF 50V 0805 | C440198
C10006, C11010, C12007 | 0805 | 3 | 2.2uF 50V 0805 | C377773
C11001, C14001, C18001, C22001, C26001, C6023, C6025 | 0402 | 7 | 10nF | C15195
C11002, C13004, C13007, C13010, C14002, C15004, C15006, C17004, C17007, C17010, C18002, C19004, C19006, C21004, C21007, C21010, C22002, C23004, C23006, C25004, C25007, C25010, C26002, C3001, C3003, C3005, C3007, C3008, C3009, C3010, C3011, C4004, C4007, C4010, C5004, C5007, C5008, C5009, C5010, C6021, C6022, C6024, C6026, C6027, C6028, C6029, C6030, C6031, C6032, C6033, C6034, C6036, C6037, C6038, C6039, C6041, C6043, C6048, C6050, C7005, C7006, C7007, C7008, C7010, C7011, C8005, C9004, C9006 | 0402 | 68 | 0.1uF
C11003, C13005, C13006, C13011, C14003, C15005, C17005, C17006, C17011, C18003, C19005, C21005, C21006, C21011, C22003, C23005, C25005, C25006, C25011, C26003, C3002, C3004, C3006, C4005, C4006, C4011, C5005, C5006, C5011, C5012, C6035, C6040, C6049, C6051, C7009, C8006, C9005 | 0603 | 37 | 10uF
C13001, C13003, C17001, C17003, C21001, C21003, C25001, C25003, C4001, C4003, C5001, C5003 | 0402 | 12 | 1nF
C13002, C17002, C21002, C25002, C4002, C5002 | 0402 | 6 | 10nF
C15001, C15003, C19001, C19003, C23001, C23003, C9001, C9003 | 0402 | 8 | 2.2uF
C15002, C19002, C23002, C9002 | 0402 | 4 | 1uF
C6001, C6002, C6003, C6004, C6005, C6006, C6007, C6008, C6009, C6010, C6011, C6012, C6013, C6014, C6015, C6016, C6017, C6018, C6019, C6020, C7004 | 0402 | 21 | 1uF 0402 | C52923
C7001, C7002 | 0402 | 2 | 5.6pF 0402 | C258497
C7003 | 0402 | 1 | 470pF 0402 | C363540
C7012 | 0402 | 1 | 4.7nF
C8001 | 0603 | 1 | 0.1uF 0603
C8002 | 0603 | 1 | 10uF 0603
D1001, D1002, D1003, D1004, D1005, D1006, D1007, D1008, D1009, D1010, D1011, D1012, D1013, D1014, D1015, D1016, D1017, D1018, D1019, D1020, D1021, D1022, D1023, D1024, D1025, D1026, D1027, D1028, D2001, D2002, D2003 | D_SOD-323 | 31 | BZT52C5V6S | C5184420
D13001, D17001, D21001, D25001, D4001, D5001 | D_SMA | 6 | D_Schottky | C22452
D6001, D6002, D6003, D6004, D7001, D7002, D7004, D7005, D7006, D7007, D7008, D7009 | 0603 | 12 | Purple LED | C7371898
D7003 | SOIC-8_3.9x4.9mm_P1.27mm | 1 | CDNBS08-SLVU2.8-4
FB7001 | 0805 | 1 | GZ2012D601TF | C1017
IC10001, IC11002, IC12001 | SOT-23-6 | 3 | TPS560430XDBVR
IC11001, IC13001, IC14001, IC15001, IC17001, IC18001, IC19001, IC21001, IC22001, IC23001, IC25001, IC26001, IC3001, IC3002, IC3003, IC4001, IC5001, IC8001, IC9001 | SOIC127P600X175-8N | 19 | INA826AIDR | C38433
IC13002, IC13003, IC17002, IC17003, IC21002, IC21003, IC25002, IC25003, IC4002, IC4003, IC5002, IC5003 | SOT-23-5 | 12 | TLV333IDBVR
IC17004, IC20001, IC24001, IC28001, IC32001 | SOIC127P600X175-8N | 5 | BD42540FJ-CE2 | C308591
IC5004 | SOT95P280X145-6N | 1 | REF35102QDBVR
IC6001 | QFP50P2200X2200X160-144N | 1 | STM32H743ZIT6 | C114408
J10001, J11001, J12001, J14001, J16001, J18001, J20001, J22001, J24001, J26001 | Screw_Terminal_3_P5.08mm | 10 | Screw_Terminal_01x03 | C8270
J15001, J19001, J23001, J9001 | AM-K-PCB | 4 | AM-K-PCB | C9900157061
J3001, J3002, J3003, J3004, J3005, J3006 | 1725038 | 6 | Screw_Terminal_01x04 | C91148
J6001 | PinHeader_2x07_P1.27mm_Vertical_SMD | 1 | Conn_02x07_Odd_Even | C3975190
J7001 | 63391601 | 1 | 6339160-1 | C125076
J8001 | BarrelJack_Horizontal | 1 | Barrel_Jack PJ-202BH | C3094841
L10001 | INDPM4040X300N | 1 | 12uH FNR4030S120MT | C167880
L11001 | INDPM4040X300N | 1 | 18uH FNR4030S180MT | C167882
L12001 | INDPM4040X300N | 1 | 33uH FNR4020S330MT | C167840
R10001, R11004, R12002 | 0603 | 3 | 22.1k 0603 | C25961
R10002 | 0603 | 1 | 51k 0603 | C23196
R10003, R11005, R12003 | 0805 | 3 | 1R 0805 | C25271
R11001, R14001, R18001, R22001, R26001 | 0402 | 5 | 200R | C25087
R11002, R14002, R18002, R22002, R26002 | 0603 | 5 | RNCF0603TKY75R0 75R 0.01% 5ppm/C | C2482496
R11003 | 0603 | 1 | 88.7k 0603 | C203875
R12001 | 0603 | 1 | 243k 0603 | C23351
R13002, R15005, R17002, R19005, R21002, R23005, R25002, R4002, R5002, R9005 | 0603 | 10 | RNCF0603TKY2K00 2k 0.01% 5ppm/C | C346578
R13003, R17003, R21003, R25003, R4003, R5003 | 0805 | 6 | 300
R13004, R13005, R17004, R17005, R21004, R21005, R25004, R25005, R4004, R4005, R5004, R5005 | 0402 | 12 | 10k 1%
R13006, R13009, R17006, R17009, R21006, R21009, R25006, R25009, R4006, R4009, R5006, R5009 | 0603 | 12 | RNCF0603TKW10K0 10k 0.01% 5ppm/C | C2482678
R13007, R6024 | 0402 | 2 | 100R 0402 | C25076
R15001, R19001, R23001, R9001 | 0402 | 4 | 10 | C25077
R15002, R19002, R23002, R9002 | 0402 | 4 | 10
R15003, R19003, R23003, R3002, R3003, R3004, R3005, R3006, R3007, R3008, R3009, R9003 | 0402 | 12 | 1M
R3001 | 0603 | 1 | PTS060301B100RP100 | C141518
R6001, R6002, R6003, R6004, R6005, R6006, R6007, R6008, R6009, R6010, R6011, R6012, R6013, R6014, R6015, R6016, R6017, R6018, R6019, R6020 | 0603 | 20 | 10R 0603 | C22859
R6021, R6022, R6023, R6025, R6026, R6027, R6028, R6029, R6030, R7002, R7004, R7006, R7009, R7010, R7012, R7019, R8006, R8007 | 0402 | 18 | 10k | C25744
R7001, R7003, R7005, R7007 | 0402 | 4 | 33R | C25105
R7008, R7015, R8005 | 0402 | 3 | 1.5k | C25867
R7011, R7013, R7016, R7018 | 0402 | 4 | 49.9 | C25120
R7014 | 0402 | 1 | 12k | C25752
R7017 | 0402 | 1 | 100R | C25076
R7020, R7021, R7022, R7023 | 0603 | 4 | 75 | C23242
R7024 | 0402 | 1 | 1M | C26083
R7025, R7026, R7027, R7028, R7029, R7030, R7031, R7032, R7033, R7034, R7035, R7036, R7037 | 0603 | 13 | 10k | C25804
R8001, R8002, R8003, R8004 | 2512 | 4 | MRF6432(2512)LR030FTS 0.030 1% | C76247
S6001 | TS1187ABAB | 1 | TS-1187A-B-A-B | C318884
T7001 | SOIC127P940X622-16N | 1 | H1102NLT | C18584
TP3001 | TestPoint_Pad_D1.0mm | 1 | TP_Board_Temp
TP7001 | TestPoint_Pad_D1.0mm | 1 | TestPoint_+12V
TP7002 | TestPoint_Pad_D1.0mm | 1 | TestPoint_+5V
TP7003 | TestPoint_Pad_D1.0mm | 1 | TestPoint_+2V5
TP7004 | TestPoint_Pad_D1.0mm | 1 | TestPoint_+3V3
TP7005 | TestPoint_Pad_D1.0mm | 1 | TestPoint_+1V024
TP7006 | TestPoint_Pad_D1.0mm | 1 | TestPoint_GND
TP8002 | TestPoint_Pad_D1.0mm | 1 | TestPoint_GND_1
U13001, U17001, U21001, U25001, U4001, U5001, U7003 | SOT-363_SC-70-6 | 7 | NTJD4001NT1G | C190019
U3001, U3002, U3003, U3004, U3005 | SOT-23-5 | 5 | 74LVC1G17 | C7836
U6002 | SOIC-8_3.9x4.9mm_P1.27mm | 1 | ADR4525 | C403914
U7001 | VQFN-24-1EP_4x4mm_P0.5mm_EP2.5x2.5mm_ThermalVias | 1 | LAN8742A
U8001 | SOT-23-6 | 1 | INA181A2 | C2058784
Y6001 | Crystal_SMD_3225-4Pin_3.2x2.5mm | 1 | SiT1602BI-21-33S-48.000000 | C1198900
Y7001 | Crystal_SMD_2016-4Pin_2.0x1.6mm | 1 | NX2016SA-25.000M-STD-CZS-1 | C843258

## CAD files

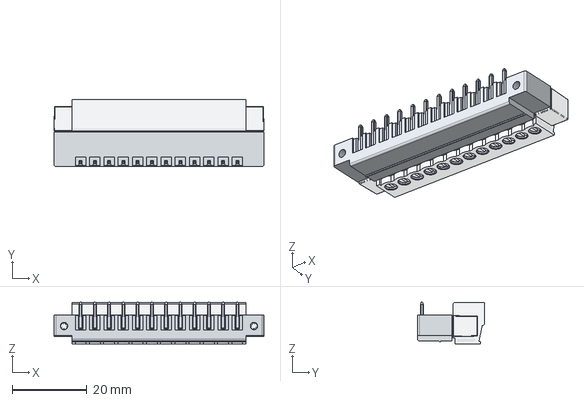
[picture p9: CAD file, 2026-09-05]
hardware/boards/deimos_daq_rev8/enclosure/terminal_block/15EDGxM-2.81-12P_assembled-Assembly.step
56.1 x 18.0 x 11.2 mm
Admi0ED050172kwy

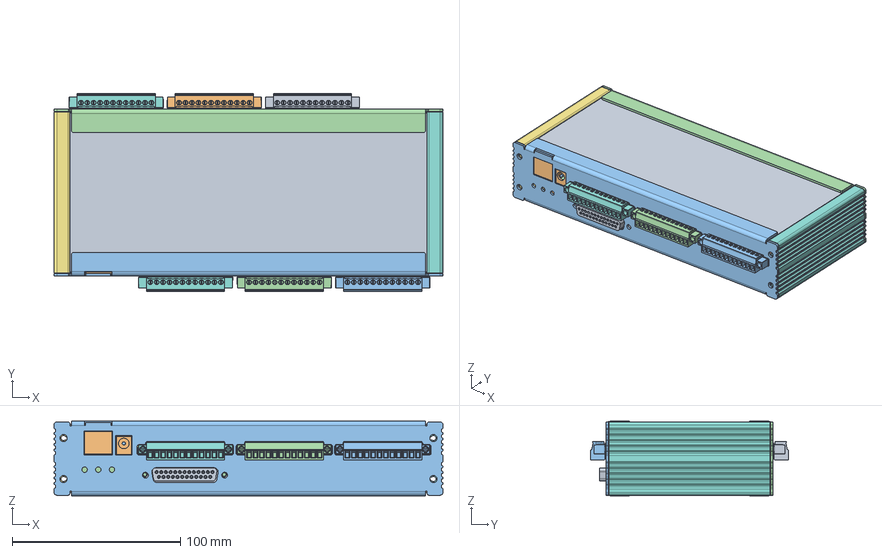
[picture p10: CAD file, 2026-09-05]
hardware/boards/deimos_daq_rev8/enclosure/deimos_daq_assembly.FCStd
231.0 x 117.4 x 44.3 mm
SOT_23
R_0805_2012Metric
C_0402_1005Metric
C_0402_1005Metric002
PinHeader_2x07_P127mm_Vertical_SMD
SOT_024
C_0603_1608Metric
C_0603_1608Metric002
R_0603_1608Metric
C_0402_1005Metric004
SOT_23_5
R_0402_1005Metric
SOT_23_006
R_0603_1608Metric002
R_0402_1005Metric002
SOT_025
R_0402_1005Metric004
C_0402_1005Metric006
R_0603_1608Metric004
R_0402_1005Metric006
D_SOD_323
C_0402_1005Metric008
C_0402_1005Metric010
R_0402_1005Metric008
R_0402_1005Metric010
C_0402_1005Metric012
SOT_026
C_0402_1005Metric014
R_0402_1005Metric012
R_0402_1005Metric014
R_0603_1608Metric006
R_0402_1005Metric016
C_0402_1005Metric016
C_0402_1005Metric018
R_0603_1608Metric008
R_0402_1005Metric018
LED_0603_1608Metric
C_0402_1005Metric020
D_SOD_324
C_0402_1005Metric022
SOT_23_007
C_0402_1005Metric024
C_0402_1005Metric026
C_0402_1005Metric028
C_0603_1608Metric004
R_0603_1608Metric010
R_0402_1005Metric020
C_0402_1005Metric030
R_0805_2012Metric002
R_0402_1005Metric022
R_0402_1005Metric024
C_0402_1005Metric032
R_0402_1005Metric026
R_0402_1005Metric028
LED_0603_1608Metric002
C_0402_1005Metric034
C_0402_1005Metric036
C_0805_2012Metric
R_0603_1608Metric012
R_0402_1005Metric030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

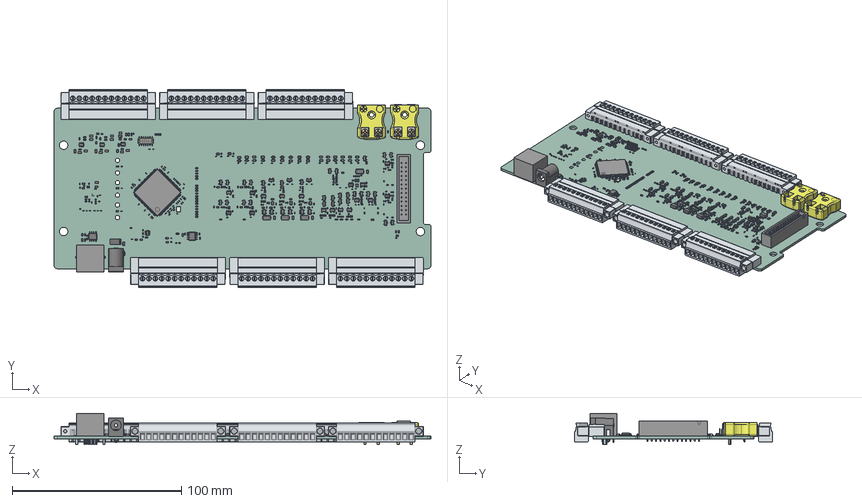
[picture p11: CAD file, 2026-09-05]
hardware/boards/deimos_daq_rev8/enclosure/deimos_daq_board.step
223.0 x 117.4 x 18.4 mm
SOT_23 x 33
R_0805_2012Metric x 22
C_0402_1005Metric x 196
PinHeader_2x07_P127mm_Vertical_SMD
C_0603_1608Metric x 19
R_0603_1608Metric x 60
SOT_23_5 x 24
R_0402_1005Metric x 106
D_SOD_323 x 17
LED_0603_1608Metric x 10
C_0805_2012Metric x 13
ASSEMBLY x 3
Assembly x 6
D_SMA x 4
R_2512_6332Metric
SOT_23_6 x 4
SOT_363_SC_70_6 x 4
SOIC_8_39x49mm_P127mm x 2
Crystal_SMD_3225-4Pin_3.2x2.5mm
LABFACILITY x 2
BarrelJack_Horizontal
L_0805_2012Metric
analog_i_PCB

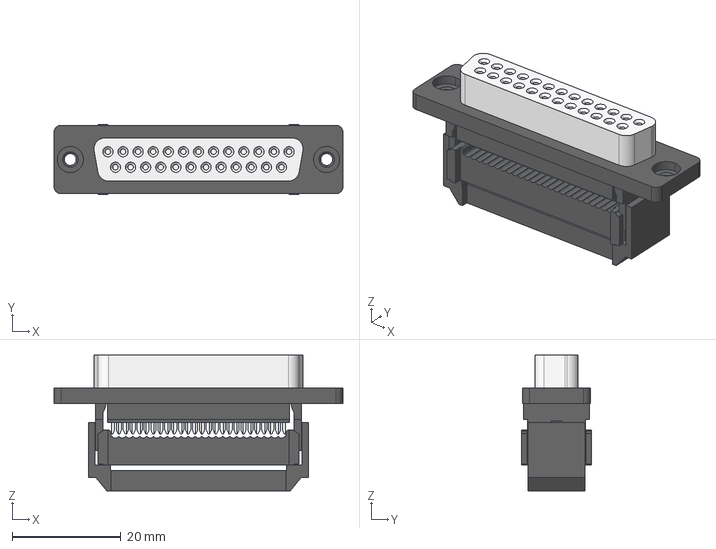
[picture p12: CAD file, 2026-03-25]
hardware/boards/deimos_daq_rev8/enclosure/dsub_idc/connector_a-dff_25_lpiii_z-unc.stp
53.0 x 12.9 x 24.9 mm

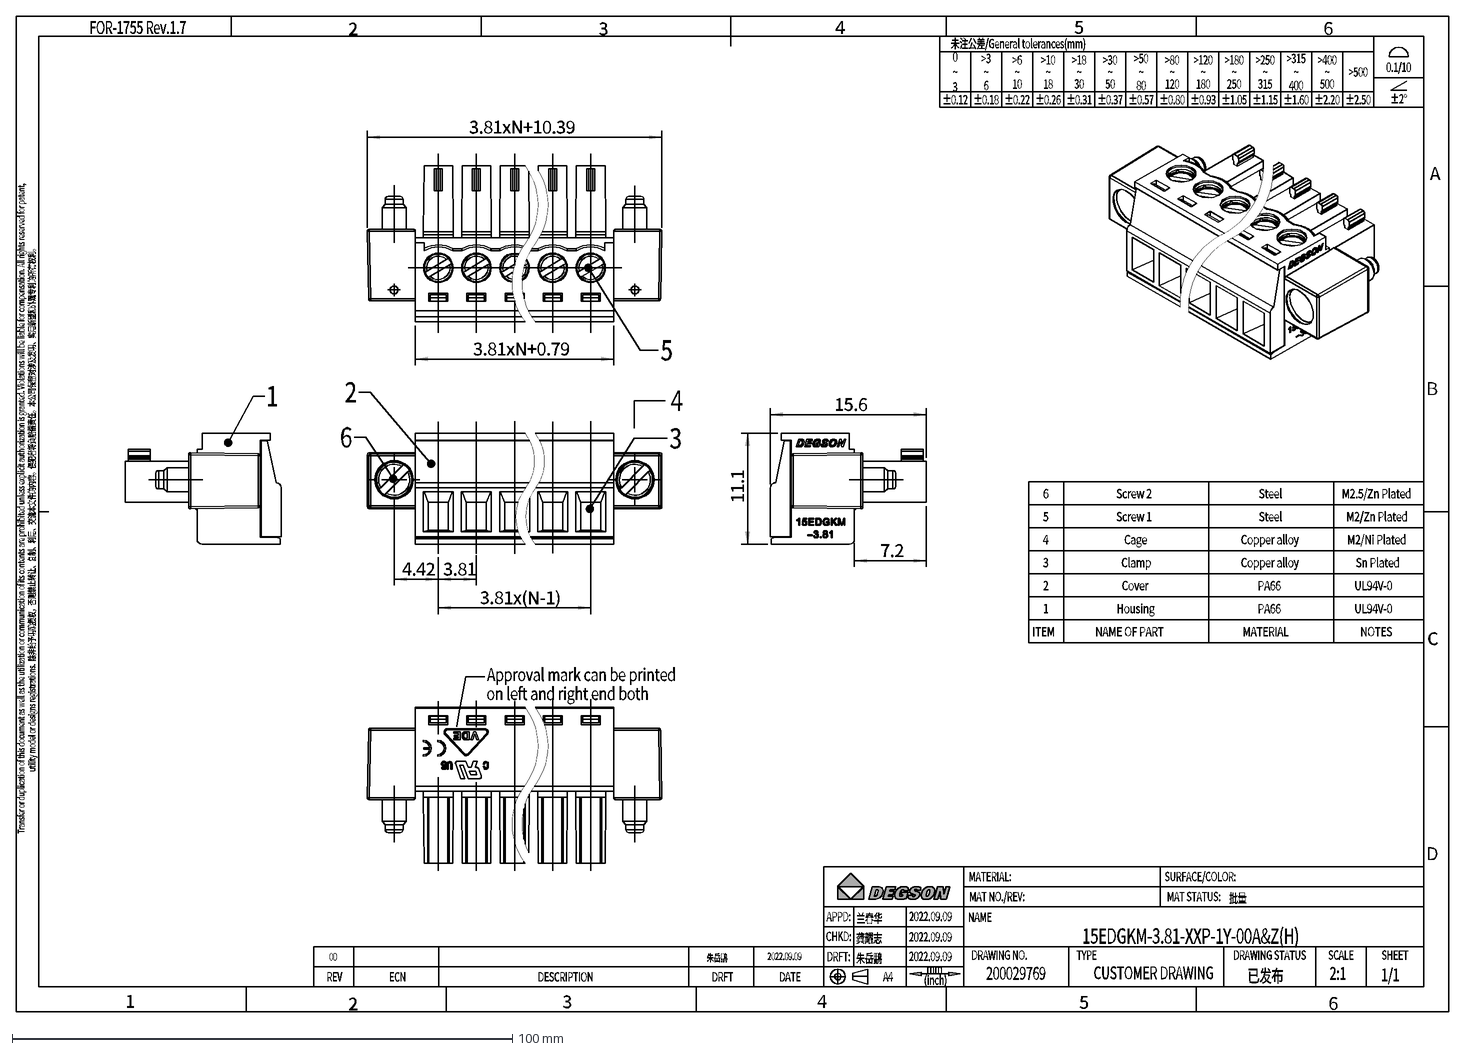
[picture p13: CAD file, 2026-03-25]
hardware/boards/deimos_daq_rev8/enclosure/terminal_block/15EDGKM-3.81-XXP-1Y-00A&Z(H).dxf
Approval mark can be printed
on left and right end both
6
Screw 2
Steel
M2.5/Zn Plated
5
Screw 1
M2/Zn Plated
4
Cage
Copper alloy
M2/Ni Plated
3
Clamp
Sn Plated
2
Cover
PA66
UL94V-0
1
Housing
ITEM
NAME OF PART
MATERIAL
NOTES
未注公差/General tolerances(mm)
0.1/10
0 ~ 3
>3 ~ 6
>6 ~ 10
>10 ~ 18
>18 ~ 30
>30 ~ 50
>50 ~ 80
>80 ~ 120
>120 ~ 180
>180 ~ 250
>250 ~ 315
>315 ~ 400
>400 ~ 500
>500
±2°
±0.12
±0.18
±0.22
±0.26
±0.31
±0.37
±0.57
±0.80
±0.93
±1.05
±1.15
±1.60
±2.20
±2.50
3.81xN+10.39
3.81
4.42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

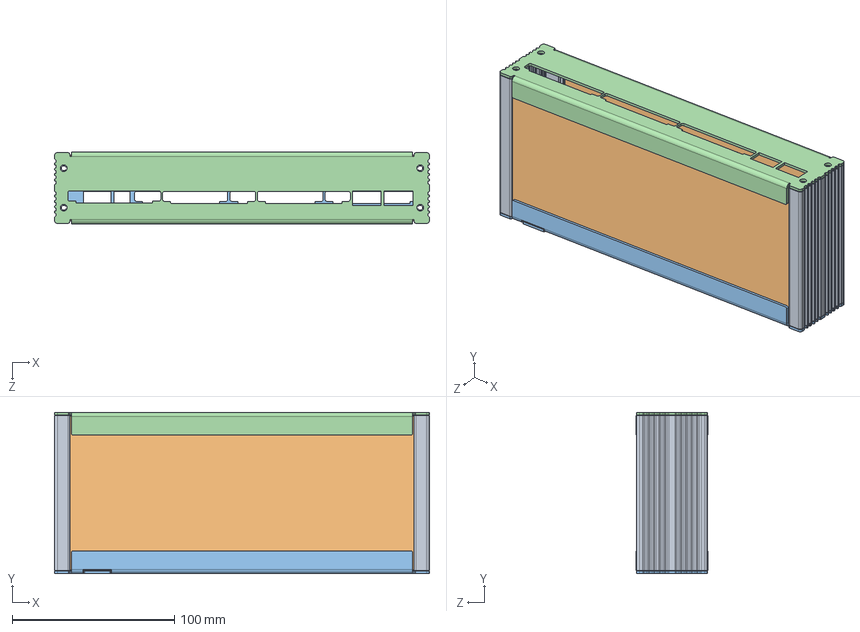
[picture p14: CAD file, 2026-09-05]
hardware/boards/deimos_daq_rev8/enclosure/DeimosDaqRev8.step
231.0 x 99.3 x 44.3 mm
1U Extruded Side x 2
Top Plate
Bottom Plate
Front Plate
Rear Plate

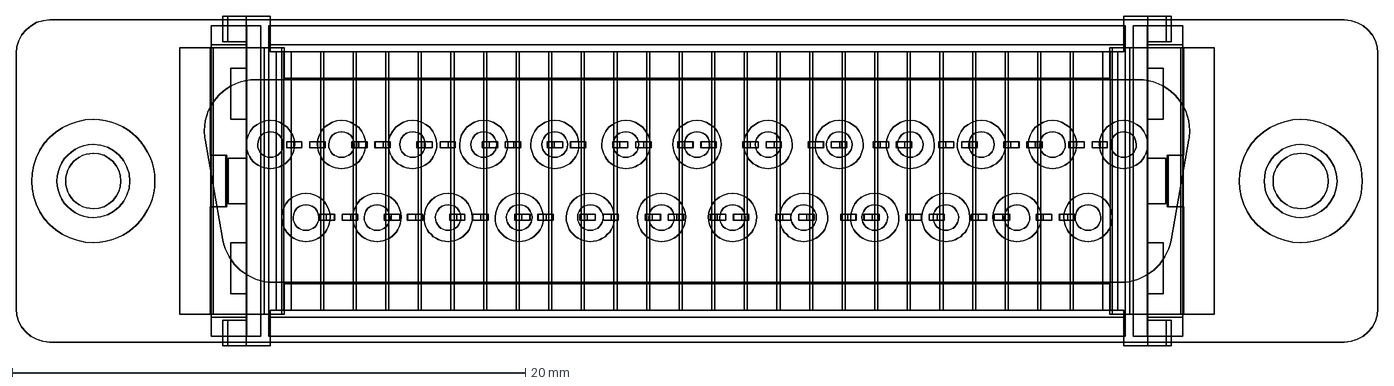
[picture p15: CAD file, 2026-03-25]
hardware/boards/deimos_daq_rev8/enclosure/dsub_idc/connector_a-dff_25_lpiii_z-unc_front.dxf
53.0 x 12.9 mm

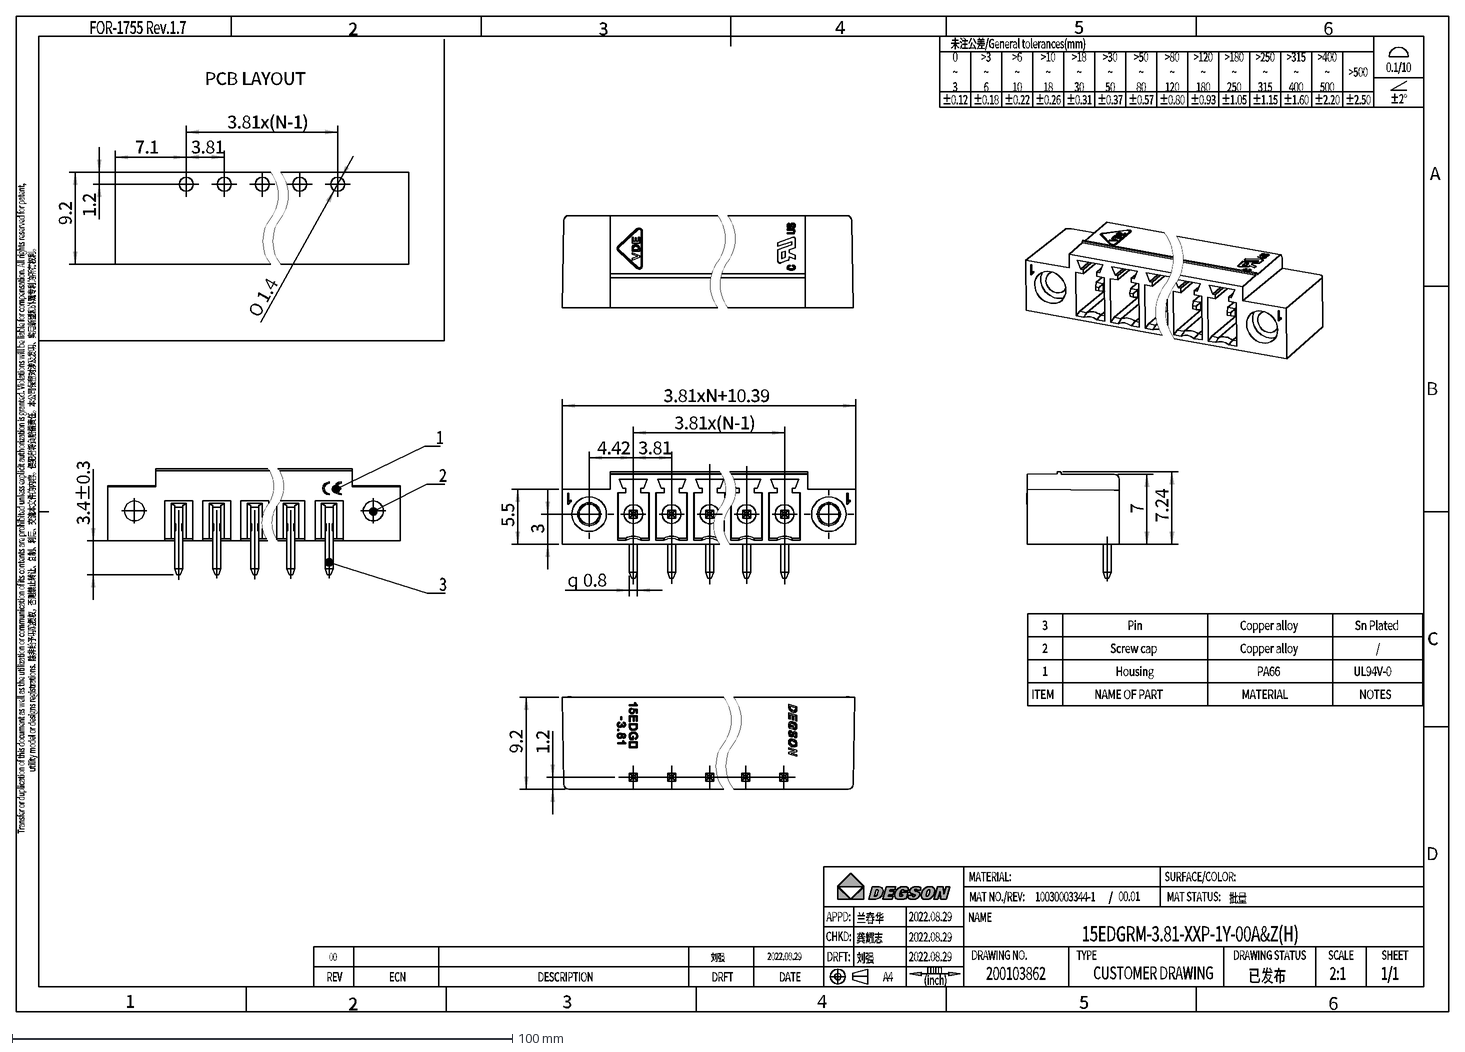
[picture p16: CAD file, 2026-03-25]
hardware/boards/deimos_daq_rev8/enclosure/terminal_block/15EDGRM-3.81-XXP-1Y-00A&Z(H).dxf
3
Pin
Copper alloy
Sn Plated
2
Screw cap
/
1
Housing
PA66
UL94V-0
ITEM
NAME OF PART
MATERIAL
NOTES
PCB LAYOUT
未注公差/General tolerances(mm)
0.1/10
0 ~ 3
>3 ~ 6
>6 ~ 10
>10 ~ 18
>18 ~ 30
>30 ~ 50
>50 ~ 80
>80 ~ 120
>120 ~ 180
>180 ~ 250
>250 ~ 315
>315 ~ 400
>400 ~ 500
>500
±2°
±0.12
±0.18
±0.22
±0.26
±0.31
±0.37
±0.57
±0.80
±0.93
±1.05
±1.15
±1.60
±2.20
±2.50
9.2
7.1
1.2
3.81
3.81x(N-1)
O
1.4
3.81xN+10.39
4.42
5.5
0.8
q
7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

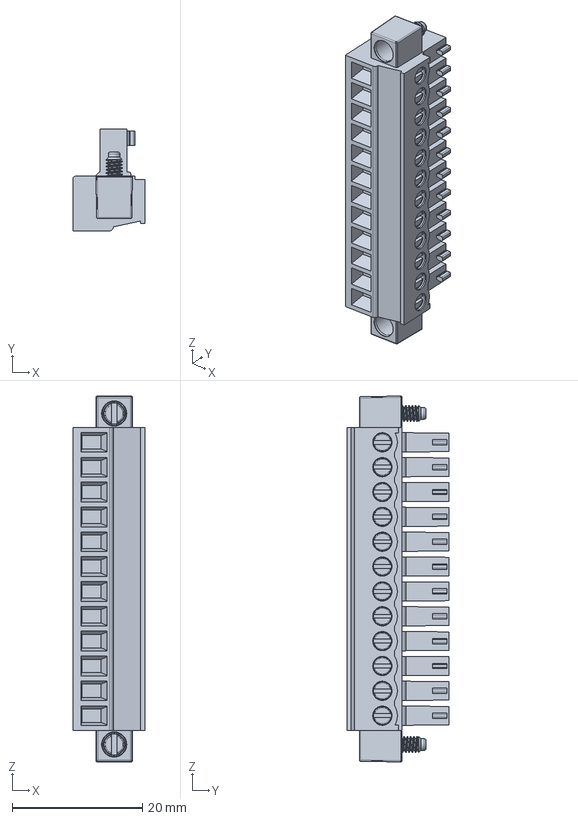
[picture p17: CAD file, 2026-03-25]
hardware/boards/deimos_daq_rev8/enclosure/terminal_block/15EDGKM-3.81-12P-1Y-00A&Z(H).stp
11.1 x 15.6 x 56.1 mm

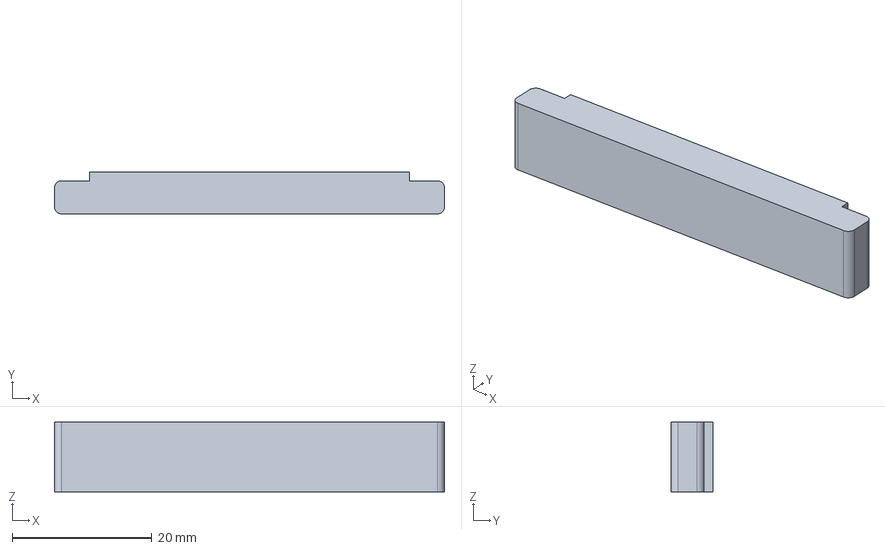
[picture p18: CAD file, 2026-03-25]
hardware/boards/deimos_daq_rev8/enclosure/terminal_block_12pos.step
55.8 x 6.00 x 10.0 mm

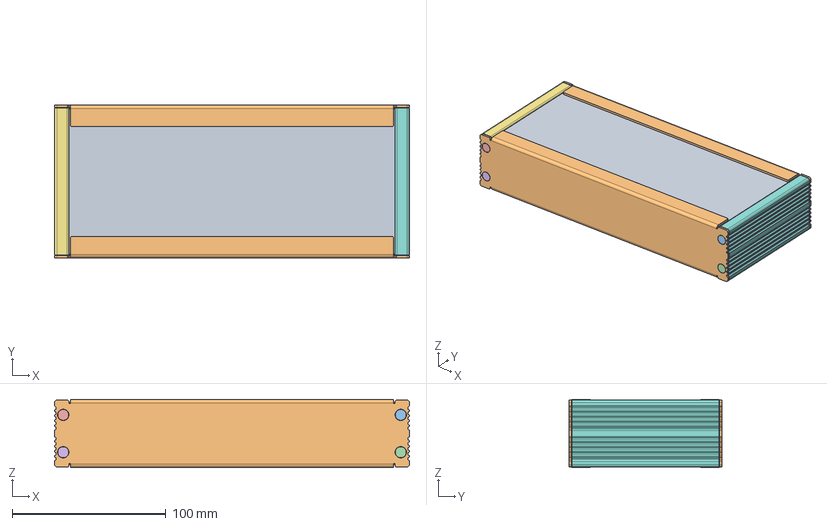
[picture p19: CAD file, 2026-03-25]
hardware/boards/deimos_daq_rev8/enclosure/deimos_daq_enclosure.FCStd
231.0 x 99.3 x 44.3 mm
Bottom_Plate
Front_Plate
6-32_3/8in_stainless_phillips_flathead_self_tapping_screw
6-32_3/8in_stainless_phillips_flathead_self_tapping_screw001
6-32_3/8in_stainless_phillips_flathead_self_tapping_screw002
6-32_3/8in_stainless_phillips_flathead_self_tapping_screw003
1U_Extruded_Side
1U_Extruded_Side001
Top_Plate
Rear_Plate
6-32_3/8in_stainless_phillips_flathead_self_tapping_screw004
6-32_3/8in_stainless_phillips_flathead_self_tapping_screw005
6-32_3/8in_stainless_phillips_flathead_self_tapping_screw006
6-32_3/8in_stainless_phillips_flathead_self_tapping_screw007

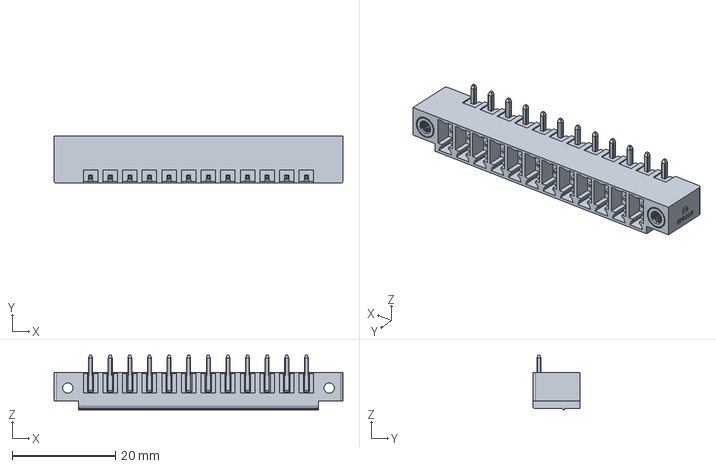
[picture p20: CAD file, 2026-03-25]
hardware/boards/deimos_daq_rev8/enclosure/terminal_block/15EDGRM-3.81-12P-1Y-00A&Z(H).stp
56.1 x 9.20 x 10.6 mm

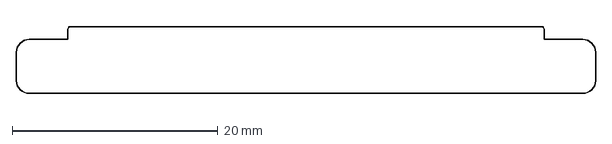
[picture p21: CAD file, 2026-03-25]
hardware/boards/deimos_daq_rev8/enclosure/terminal_block_12pos_cutout_clearance.dxf
56.3 x 6.50 mm

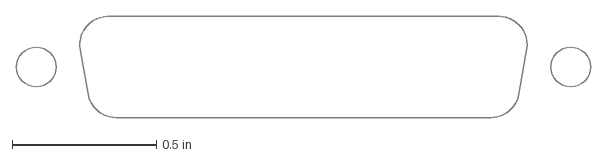
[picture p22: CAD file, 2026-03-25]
hardware/boards/deimos_daq_rev8/enclosure/dsub_idc/connector_cutout_0p5mm_clearance_inner_screw_inches.dxf
1.99 x 0.35 in

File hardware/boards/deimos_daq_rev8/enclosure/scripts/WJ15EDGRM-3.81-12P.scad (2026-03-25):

//
// Final enclosure interface model
// 12-position, 3.81 mm pitch pluggable terminal block
//
// Correct shape:
//   • full outer silhouette used for enclosure cutout
//   • lowered top sections on the OUTER 5 mm of each side
//   • raised full-height center section
//   • R1 fillets on all four OUTER corners
//   • optional 3D reference model
//

// ---------------- Parameters ----------------

pins = 12;
pitch = 3.81;

// From drawing
body_w = pins * pitch + 0.88;
ear_each = 4.60;

// Measured
overall_h = 6.00;      // full center height
outer_notch_w = 5.00;  // lowered region width from each outer edge
notch_d = 1.25;        // amount lowered from the top
corner_r = 1.00;

// Simplified 3D reference depth
body_depth   = 7.0;
flange_thick = 3.0;

// User-adjustable
clearance = 0.20;


// ---------------- Derived ----------------

overall_w = body_w + 2 * ear_each;


// ---------------- Helpers ----------------

function arc_pts(cx, cy, r, a1, a2, n=12) =
    [ for (i = [0:n])
        let(a = a1 + (a2 - a1) * i / n)
        [cx + r * cos(a), cy + r * sin(a)]
    ];


// ---------------- 2D Profile ----------------

module panel_cutout_profile(extra = 0) {
    w  = overall_w + 2*extra;
    h  = overall_h + 2*extra;
    nw = outer_notch_w + extra;
    nd = notch_d + extra;
    r  = corner_r + extra;

    xL = -w/2;
    xR =  w/2;
    yB = -h/2;
    yT =  h/2;        // full-height center top
    yN = yT - nd;     // lowered outer-top level

    pts = concat(
        // bottom edge
        [[xL + r, yB]],
        [[xR - r, yB]],

        // bottom-right radius
        arc_pts(xR - r, yB + r, r, -90, 0),

        // right side up to lowered-top radius start
        [[xR, yN - r]],

        // top-right outer radius (to lowered top)
        arc_pts(xR - r, yN - r, r, 0, 90),

        // lowered right outer section
        [[xR - nw, yN]],

        // step up to full-height center
        [[xR - nw, yT]],

        // full-height center top
        [[xL + nw, yT]],

        // step down to lowered left outer section
        [[xL + nw, yN]],

        // lowered left outer section
        [[xL + r, yN]],

        // top-left outer radius (from lowered top to left side)
        arc_pts(xL + r, yN - r, r, 90, 180),

        // left side down to bottom-left radius start
        [[xL, yB + r]],

        // bottom-left radius
        arc_pts(xL + r, yB + r, r, 180, 270)
    );

    polygon(points = pts);
}


// ---------------- 3D Reference ----------------

module connector_reference_3d() {
    union() {
        linear_extrude(height = flange_thick)
            panel_cutout_profile();

        translate([0, 0, -body_depth])
            linear_extrude(height = body_depth)
                panel_cutout_profile();
    }
}


// ---------------- Output ----------------

// 3D reference model
connector_reference_3d();

// 2D enclosure cutout instead:
// panel_cutout_profile(clearance);

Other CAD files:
hardware/boards/deimos_daq_rev8/enclosure/terminal_block/15EDGxM-2.81-12P_assembled.FCStd
hardware/boards/deimos_daq_rev8/enclosure/terminal_block/15EDGKM-3.81-12P.FCStd
hardware/boards/deimos_daq_rev8/enclosure/terminal_block/15EDGRM-3.81-12P.FCStd
hardware/boards/deimos_daq_rev6/enclosure/deimos_daq_enclosure.stp
hardware/boards/deimos_daq_rev7/enclosure/Deimos_Daq_Rev7_Bare_95p5_x_231_Rev1_as_quoted.step
hardware/boards/deimos_daq_rev7/enclosure/as_ordered/Deimos Daq Bare 95p5 x 231 Rev7.step
hardware/boards/deimos_daq_rev8/enclosure/deimos_daq_board.FCStd

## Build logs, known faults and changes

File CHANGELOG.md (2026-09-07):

# Changelog

## 2026-09-05 0.21.2

* Add `deimos_procedures` package and move bench/test/cal procedures from `deimos/examples`
* Centralize workspace deps
* Add new photos and updated specs to website

## 2026-09-05 Hardware Rev 8.0.0, Software 0.21.1

Tooling: Same as 6.0.1

Changes

* Firmware
  * rev7 firmware
    * Use `qei` HAL module to configure encoder 
  * Add rev8 firmware
    * Copy forward from rev7
    * Replace frequency and pulse counter inputs with more encoders
    * Use `qei` HAL module to configure encoders
* Software
  * Add rev8 peripheral modules, packets, and standard calcs
* Hardware
  * [x] Improve digital inputs with 22k resistor and schottky clamp to 3.3V
  * [x] Replace frequency and pulse counter inputs with more encoders

##### New encoder pinout

  | Encoder | Phase | MCU pin | Package pin | Timer channel | Alternate function |
  |---|---|---:|---:|---|---:|
  | Encoder 0 | A | PE9 | 60 | TIM1_CH1 | AF1 |
  | Encoder 0 | B | PE11 | 64 | TIM1_CH2 | AF1 |
  | Encoder 1 | A | PC6 | 96 | TIM8_CH1 | AF3 |
  | Encoder 1 | B | PC7 | 97 | TIM8_CH2 | AF3 |
  | Encoder 2 | A | PB6 | 136 | TIM4_CH1 | AF2 |
  | Encoder 2 | B | PB7 | 137 | TIM4_CH2 | AF2 |
  | Encoder 3 | A | PB4 | 134 | TIM3_CH1 | AF2 |
  | Encoder 3 | B | PB5 | 135 | TIM3_CH2 | AF2 |

  ##### New PWM pinout

  | PWM output | MCU pin | Package pin | Timer channel | Alternate function | Change |
  |---|---:|---:|---|---:|---|
  | PWM0 | PE6 | 5 | TIM15_CH2 | AF4 | Moved from PC7/TIM3_CH2 |
  | PWM1 | PB14 | 75 | TIM12_CH1 | AF2 | Unchanged |
  | PWM2 | PB8 | 139 | TIM16_CH1 | AF1 | Unchanged |
  | PWM3 | PB9 | 140 | TIM17_CH1 | AF1 | Unchanged |

## 2026-08-26 0.21.0

* deimos
    * !Refactor Calc trait and its interface with the calc orchestrator to reduce complexity
        * Retain all outputs by default; outputs can be reduced explicitly with a channel filter dispatcher
        * Remove string-based unit-of-measure labeling for now in favor of a more complete system later
        * Eliminate mutability of calcs during run; mutable state is contained in a `CalcFn` closure that lives only for the duration of the run
    * Add calc arch doc
    * Add min and max calcs for min and max of a set of channels
    * Add `Hysteretic` bang-bang controller calc
    * Add `bangbang.rs` example

## 2026-08-14 Hardware Rev 7.0.3

* [x] Flip orientation of IDC header
* [x] Resolve crosstalk between 35mV channels and thermocouple channels
    * Buffer shared 1.024V offset ref at each 35mV frontend
* [x] Improve light-pipe LED brightness
* [x] Improve 24V supply filtering
    * Need better immunity to conducted EMI from the upstream power supply 
    * Just added more capacitance for now
* [x] Exclude testpoints from BOM

## 2026-08-08 0.20.0

Addition of laboratory instruments interface with concrete implementations for Keithley DMM6500 bench multimeter and Siglent SDG2042X signal generator via SCPI/TCP.

* Rev7 Firmware
    * Normalize operating output commands before validation
    * Add DAC calibrations
* deimos
    * Add design doc for third-party instrument integrations
    * Add `peripheral::instruments` module with laboratory instrument wrappers and supporting partial-coverage SCPI implementation
    * Add concrete `Peripheral` implementations for DMM6500 and SDG2042X
    * Add example use of DMM6500 and SDG2042X
    * Clamp peripheral output commands and safe-state outputs commanded with NaN
    * !Move thread-channel sockets to their own SPSC channel pool keyed by PeripheralId instead of sharing the user channel MPMC pool
    * !Move calibration procedure from peripheral module to example
    * Update calibration procedure to use automated measured-source procedures for voltage inputs, DAC outputs, and thermocouple inputs
* deimos_website
    * Add instrument folders and cal sheets for new instruments
    * Update calibrations for SN3 with latest procedure and equipment
    * Add modbus page

## 2026-08-01 0.19.0

Firmware overhaul for the Rev7 DAQ.

* Rev 7.0.2 Hardware
    * Remove cathode cap from shunt reg to restore stability
    * Update layout and fab files
    * Add as-ordered enclosure with eth cutout mod from protocase
    * Fix graphics typo on enclosure
* Rev7 Firmware 0.8.0
    * Use a more robust synchronous sampling scheme
        * 9kHz synchronous oversampling up to 3kHz
        * Synchronous sampling from 3kHz to 8kHz
        * This gives lower jitter and more well-posed cycle timing margin than high-frequency oversampling
        * Now have only one systick timer-driven interrupt; TIM2 interrupt removed entirely
    * Add modbus support
    * Characterize cycle timing margin and stack usage
    * Add packet magic numbers and validation
    * Do first-line calcs in firmware instead of software
        * Calibrations, voltage conversions, resistance, board RTD, thermocouples, board current and voltage
        * This is required for modbus operation to be useful
    * Require calibrated firmware for normal deimos and modbus operation
    * Add sample_time_ns as an output marking as close as possible to the start of the latest sample
    * Add packet processing budget per cycle to avoid potentially unbounded loop in smoltcp processing
        * This eliminates a potential packet-storm freeze
* deimos_shared
    * Add `calcs` module with new thermocouple and RTD functions optimized for firmware
        * Use verified regular grid B-spline fit for thermocouple inverse function
        * For RTDs, use IEC 60751 Callender-Van Dusen function fit to the ITS-90 data
            * This mitigates the problems from the tables being published with 2 decimals
    * Refactor rev7 peripheral module and add modules for modbus and sampler timing arithmetic
* deimos
    * Replace RTD and thermocouple calcs with ones re-exported from deimos_shared
        * This makes them available to both firmware and software

## 2026-07-19 0.18.1

* Rev7 hardware
    * Finish pcb layout updates & re-generate fab files
    * Update enclosure graphics
* Rev7 firmware
    * Move `sample()` function with DSP pipeline into ITCM memory
    * Move `Net::poll` function with bulk of networking logic into ITCM
    * This prevents them from being ejected from cache, or taking up space in cache
    * This should allow all remaining Operating-state code to remain in L1 cache (16kB)
* deimos
    * Update an example and reqwest dep

## 2026-06-28 0.18.0

This update adds calibration procedures for the Rev7 and wires
calibration handling into the controller, calc orchestrator,
and peripheral trait. It also adds and ultra-lightweight, open-access
calibration database as part of the static site, populated with the
first set of calibrations.

* deimos
    * Add Rev 7.0.0 calibration procedure
    * Add calibration record structs
    * Remove initial calc evaluation before entering control loop
        * No longer needed, since we now wait until all peripherals have responded to start calcs
        * Removing this makes software-side filter initialization instant on first cycle
    * Add supporting functions to thermocouple and RTD calc modules
    * !Replace calc::tc_ktype lookup tables with ITS-90 polynomial fits
        * This update includes a change in handling of cold-junction temperature: the 1D inverse fit is now used to calculate the expected cold-junction voltage, which is then subtracted from the sensed voltage before using the forward fit to calculate the hot-junction temperature
        * This produces better match against the calibrator below -40C, where the tabulated cold-junction error goes toward zero.
    * !Update rev7 standard calcs to add conversion from ADC voltage to sensed voltage as a discrete step, and calibration application as another step
    * !Update `Calc::standard_calcs` signature to include calibration json data
    * !Update `peripheral::PluginFn` closure signature to take `PeripheralId` instead of `BindingOutput`
    * !Add calibration-related methods to Peripheral trait
    * Add `replay` module and `Controller::replay()` to support re-running the latest calc graph over already-collected raw data
    * Add calibration-related fields on `controller::Context`
    * Update `CsvDispatcher` to join the thread synchronously during terminate
        * Ensures that data will be present on disk if used immediately after the run; otherwise, the dispatcher thread may still be busy flushing its buffer to disk
    * Update rustdoc theme
    * Add more python type stubs and re-export DeimosDaqRev7 peripheral class
    * Improve python docs
* deimos_website
    * Add awesome-pages and pagetree plugins
    * Add records/ route and store calibration data and reports there
    * Update style and content
* deimos_shared
    * Update rev7_bode to export html to website & remove brittle SVG export
    * Update rustdoc theme
* deimos_numerics
    * Update rustdoc theme

## 2026-06-08 0.17.0

This update moves the rev7 firmware's filter construction and runtime
from `flaw` to `deimos_numerics`, and from interpolated to analytic
construction. The filter construction pipeline is moved to deimos_shared
and adds access to filter transfer functions on the application side
that exactly match the ones used by the firmware, along with an example
that plots those transfer functions.
It also migrates `deimos_website` into this repo.

* deimos
    * Update Butter2 calc to use deimos_numerics delta-form SOS filter with 64-bit floats
    * Update timing controller to use deimos_numerics median filter
    * Update LowPassDispatcher to use deimos_numerics filter
    * Minor cleanup of construction of rev7 standard calcs
    * Add import error on detection of irresponsible error suppression via python -O
* deimos_numerics
    * !Add #[non_exhaustive] on `LtiError` and an error variant to support analog helpers
    * Add `DeltaSOS::set_steady_state` for initializing filters to steady state
    * Add MedianSort method backed by bounded-loop insertion sort for small arrays
    * Add Sallen-Key analog transfer function
    * Add light mode toggle to numerics explorer example
* deimos_shared
    * Add transfer functions and bode data for rev7
    * Add rev7_bode example with plots of rev7 transfer functions
    * Add rev7 board constants and filter module
* rev7 firmware 0.7.0
    * Add 32kB heap link region
    * Link with flip-link to grow stack away from heap
    * Add embedded-alloc and use Llff allocator
    * Use deimos_numerics Delta-SOS butter2 filters initialized live analytically
    * Remove butter1 fallback path for low frequency operation
    * Move board constants and filter construction to deimos_shared

## 2026-05-24 0.16.2

Initial addition of `deimos_console`, an egui-based realtime plotting client
contributed by Jon Bass (@firstmorecoffee).

* deimos
    * Add multicast reporting system and `ReportingDispatcher` that distributes data and schemas for clients on the local network.
    * Resolve new clippy lints.
* deimos_console
    * Initial addition of realtime plotting client.
* deimos_numerics
    * Add notes about unused-import warnings in test modules.
* Deimos DAQ Rev7
    * Updated enclosure and as-quoted enclosure CAD.

## 2026-05-01 0.16.1

Initial addition of `deimos_numerics`, a wasm-compatible, no-std-compatible, and partially no-alloc-compatible numerics and control systems library.

## 2026-04-02 0.16.1, rev7 firmware 0.6.0

This update continues the buildup of the firmware for the rev7,
including support for statically-addressed networks without DHCP
and direct ethernet connection to the control computer.

While statically-addressed networks assembled using ARP are usually limited
by ARP storm instability, this implementation mitigates that failure mode
by checking a bounded number of candidate addresses instead of broadcast scanning.
For the same reason, no broadcast gratuitous ARP is sent when an address is claimed.

### Added

* deimos
    * `peripheral::deimos_daq_rev7` module with updated default calcs
* deimos_shared
    * Add function for deriving static fallback address candidates from MAC address
* rev7 firmware
    * Plumb in the read, write, and packet formation for the new gpio pins
    * Improve handling of mutable statics for eth driver
    * Update to 2024 edition
    * Make `Net` fields private and access via functions
    * Support use on static networks in the 169.254.x.y block without a DHCP server
        * This also supports direct-to-computer ethernet connection, which is treated as a static network
    * Add `IpAssignment` address assignment state machine
        * Start with 3 static address candidates in the 169.254.x.y block derived from MAC
            * This is the block used automatically by Windows and MacOS, and can be manually configured for linux
        * Do a 1 ARP probe of the static address and watch for 250ms to check if it is taken
        * If a candidate is taken, move to the next and attempt ARP probes
    * In Connecting, immediately assign a static address unless a DHCP address has already been established
        * This allows immediate reconnection after a power or eth interruption on static networks
    * Connecting now immediate transitions to Binding with either a static or dynamic address assigned
    * In Binding, Configuring, and Operating, when polling IP address config, advance
      the address state machine and check for ARP probe and DHCP responses
        * This is a slight change in behavior: DHCP maybe configured at any time during Connecting, Binding, or Configuring
        * If a DHCP address is configured during Operating, it is not applied until the next return to Connecting in order to avoid disrupting an active operation that started with a static address
        * If a DHCP address is configured on one network and then the peripheral is moved to a different static network, it will maintain its DHCP address until the end of its lease (which could be a full day), or, more likely, until a reset or power cycle
    
## 2026-03-25 Rev7 Hardware & Firmware

### Added - Deimos DAQ Rev7 Hardware & Firmware

* Firmware: first cut with extra GPIO pins broken out
* Hardware
    * Tooling: Same as 6.0.1
    * [x] Consider removing 660x channel (is the input offset too much for this gain level?)
        * Replaced with a second 25.7x channel
    * [x] Add IDC breakout to panel-mount dsub connector for voltage measurement block
    * [x] Use pluggable terminal blocks instead of lever-wire to reduce FOD intrusion risk
    * [x] Add 4x GPIO pin outputs and 2x GPIO inputs
    * [x] Add negative voltage pulldown on DAC pins to allow reaching true rail in buffered mode
        * [x] Place a 3k pulldown and a diode from ground somewhere that's easy to desolder in case it becomes a problem
    * [x] Improve overvoltage protection
        * Added regulated OVP rail to reduce clamp voltage
    * [x] Move right side connectors inboard to make room for label graphics
    * [x] Add footprint for SMFLP flexible light pipe
    * [x] Refactor layout of base module to be more compact
    * [x] Move base module ethernet RMII traces to inner layer for EMI
    * Enclosure
        * [x] Update for new connectors
        * [x] Add light pipe indicator hole

## 2026-03-21 deimos 0.16.0

### Changed

* Handle peripheral discovery across multiple eth interfaces or subnets
    * This allows use on routers operating in bridge mode with their own NAT layer and subnet
* Support selecting a specific eth interface or subnet
    * This allows the industrial-style dual-interface where the control network is on its own network interface, separated from the global internet
* Add dot/graphviz export for calc orchestrator and sequence machine
* TSDB dispatcher upgrades
    * Set chunk size for TSDB dispatcher to 25% of retention duration by default
        * This resolves disk space errors caused by the database failing to clear any stale data due to the requirement that the entire chunk be stale
    * Use Duration for setting retention duration to allow non-integer hours
    * Update retention duration when reusing a table
    * Add optional table name suffix
        * Allows multiple dispatchers to target the same database, for example, to write a second downsampled table with a longer retention time
* CSV upgrades
    * Add optional file name suffix

## 2026-01-04 Rev6 Firmware 0.5.1

### Changed

* Use buffered mode for DACs again
    * Unbuffered mode produces some voltage error
    * Buffered mode rails at 20mV on the low end, but this will be resolved in hardware in a later rev

## 2026-01-01 deimos 0.15.0

Broad refactor and many new features to improve usability of software interface. 

### Added

* Rust
    * Add `python` feature for building python bindings
    * Add `controller::nonblocking` module with machinery for running the controller on a separate thread
        * Includes external termination signal and live manual read/write handles
    * Add reconnection logic to controller
        * `LossOfContactPolicy::Reconnect` allows attempting reconnection after losing contact with peripherals during run
        * This provides robustness to IP address reconfiguration, hot-swapping modules, etc
        * Provide a timeout duration or allow indefinite reconnection attempts
    * Add `peripheral::hootl` module with machinery for building software mockup wrappers of hardware
        * Includes UDP loopback implementaiton to mimic hardware as fully as possible
    * Add `python` module with python bindings
    * Add `socket::orchestrator` module with new layer of socket abstraction
        * Option 1 (used for Performant operation mode) is similar to previous (synchronous nonblocking rx/tx)
        * Option 2 (used for Efficient operation mode) uses a fan-in thread channel system to defer rx waiting to OS scheduling and places sockets on separate threads during run
    * Add `socket::thread_channel` module with a Socket implementation that uses a user channel for comms
        * This supports HOOTL testing on non-unix platforms with the unix socket is not available
    * Add `socket::worker` module with socket thread workers for use with Efficient operation mode fan-in pattern
    * Add `Efficient` operation mode
        * Uses OS scheduling instead of busy-waiting, and thread channel fan-in pattern for comms instead of polling
        * Reduces CPU usage to around 1% at the expense of degraded performance above 50Hz
        * Does not pin core affinity
    * Add `dispatcher::latest` for extracting the latest values during run
    * Add `dispatcher::low_pass` wrapper for running a low-pass filter on each channel
    * Add `dispatcher::decimation` wrapper for taking every Nth value
    * Add `dispatcher::channel_filter` wrapper for selecting only specific channels to be passed along
* Python
    * Add python bindings and type stubs
    * Add python examples, tests, and deployment workflow

### Changed

* Rust
    * Remove `calc::Orchestrator` from public API and rename to `CalcOrchestrator`
    * Refactor `Socket` trait for new optional fan-in system
    * Refactor `Controller` and `Context`
        * Accommodate both Performant and Efficient operating methods
        * Implement reconnection logic
        * Implement nonblocking operation and external read/write/stop handles
        * Fine-tune control loop performance to reduce cycle busy time to about 12 microseconds and eliminate context switching opportunities from main loop, allowing at least 20kHz stable operation of control software under real-life conditions with 7 DAQs attached on UDP and 447 channels of data stored (now limited primarily by hardware performance)
        * Store, add, and remove sockets and dispatchers by name
    * Refactor `Calc` and `Dispatcher` implementations to return `Box<Self>` from `new` to reduce boilerplate
    * Refactor `logging` module to allow reentrant runs without conflict due to duplicate logger setup
    * Refactor `calc::sequence_machine` module into a folder with multiple files and remove Timeout::Error option
    * Set up workspace versioning
    * Update and unpin dep versions to be more friendly to use within a larger project
    * Gate unix socket functionality behind `#[cfg(unix)]` to allow Windows builds to run
    * Improve logging and error handling across entire project
    * Use `x86-64-v3` reference cpu target instead of manually enabling instruction sets
    * Update readme
    * Move `dispatcher::tsdb::Row` up to `dispatcher` for reuse
    * Add live-reading handle to `dispatcher::df` for use from python
    * Add `Send + Sync` to trait bounds for `peripheral::PluginFn` to support nonblocking run method
* Hardware
    * Improve manufacturability of silkscreen on Deimos DAQ Rev6
* Firmware
    * Update Deimos DAQ Rev6 firmware to use latest version of `flaw` filtering library

### Removed

* Rust
    * Remove `CalcProto` and `PeripheralProto` object prototyping interfaces and related types and constants.
    * Remove `Orchestrator` (from public API)

## 2025-10-26 Deimos DAQ Rev 6.0.2 hardware

### Changed

* Deimos DAQ Rev 6
    * Remove trace that bridged 3.3V and 1.024V rails due to autocleanup failure during hierarchical layout update
    * Re-generate fab files

## 2025-10-16 deimos 0.14.0

### Added

* Add `math` and `math::polynomial` modules with polynomial evaluation and curvefitting

### Changed

* `calc::Polynomial`
  * !Remove `eval_poly` method and defer to `math::polyval`, which uses mul_add operations
  * Add `fit_from_points` method for initializing coeffs from calibration points

## 2025-10-14 deimos 0.13.0

### Added

* Add polynomial calc

### Changed

* !Make logger guards local instead of global statics to allow reconfiguring logging between sequential ops
* !Return log file location and guards from logger setup
* Name log file after op
* Append logs instead of truncating
* Remove thread priority functionality that requires elevated permissions
* Instead of using every second core for auxiliary functions, reserve the first 2 cores
  for the main thread and cycle auxiliary functions over all the remaining cores
* Improve logging and error handling

## 2025-10-13 deimos 0.12.0

### Added

* Add logging module with terminal and file logging setup using nonblocking `tracing` ecosystem

### Changed

* !Calc trait methods now return Result types
* !Controller::{bind, scan} now return Result types and map previous panic behavior to errors
* Orchestrator methods map more cases to Err instead of panic
* Terminal printing in Controller and examples replaced with logging
* Controller::terminate rolls up all errors before returning
* In Controller::run, when attempting to send data to dispatchers, an attempt is made to send
  data to every dispatcher before returning an error rollup if any errors occurred
* In Controller::run, log malformed or unexpected packets that were previously ignored
* Initialize tsdb dispatcher on main thread and propagate initialization errors instead of panicking worker thread
* Propagate errors instead of panicking when possible in CSV dispatcher

## 2025-10-13 deimos 0.11.3

### Added

* `calc::butter` module with `Butter2` second order butterworth filter calc
* `branches` dep for branch hinting filter initialization

### Changed

* Apply 1Hz Butter2 filtered `board_rtd_filtered` channel in rev6 standard calcs
* Use filtered board temperature for thermocouple cold-junction correction

## 2025-10-12 deimos 0.11.2, deimos_shared 0.5.1, Deimos DAQ Rev 6.0.1 hardware and firmware

Tooling
* ubuntu 24.04
* kicad 8 with hierarchical PCB plugin
* protocase designer v7.2.1 linux version
  * Run like `LD_LIBRARY_PATH=/opt/protocasedesigner/lib/app/natives/occjava/linux-x86_64/ /opt/protocasedesigner/bin/ProtocaseDesigner` to resolve link path issue for java runtime
* freecad 1.0.2

### Added

Hardware
* Deimos DAQ Rev 6.0.1 schematic and layout
    * [x] Replace overvoltage protection diodes from leaky zeners to low-leakage JFET clamp
    * [x] Add 5V LDO as supply for resistance amplifiers to restore gate voltage margin
    * [x] Use smaller resistor values for resistance amp common-mode filter
        * INA826 has significant input bias current (~25nA) which makes a nontrivial voltage across 20k resistance
    * [x] Disable internal buffer for DAC to allow rail-to-rail operation
        * Buffered mode min and max voltages are 20mV off the rails
        * Can rely on external buffer that is already implemented for overvoltage protection
* Controller Base Rev 16.0.1
    * [x] Remove unnecessary clamping diodes
    * [x] Remove unnecessary eth PHY crystal load caps
    * [x] Clean up ethernet layout

Software & Firmware
* deimos_daq_rev6 firmware
    * Rolled forward to latest `interpn` and `flaw` versions w/ perf improvements; ~30% increase in cycle timing margin
* deimos
    * Add rev 6 firmware and calc plugin
* deimos_shared
    * Add rev 6 packet formats

Analysis
* Added JFET diode clamp spice model

## 2025-09-19 deimos 0.11.1, Deimos DAQ Rev 6.0.0 hardware

Tooling
* ubuntu 24.04
* kicad 8 with hierarchical PCB plugin
* protocase designer v7.2.1 linux version
  * Run like `LD_LIBRARY_PATH=/opt/protocasedesigner/lib/app/natives/occjava/linux-x86_64/ /opt/protocasedesigner/bin/ProtocaseDesigner` to resolve link path issue for java runtime
* freecad 1.0.2

### Added

* Enclosure design (protocase)
* 3D assembly (freecad)
    * With STEP exports from protocase and kicad
* Rev6 schematic and layout
    * [x] Add damping in RTD current sink control loop
        * Existing circuit sees about 60mV peak-to-peak oscillation on the FET gate due to lack of damping in loop
        * Add integrator-style filter
        * Resistor from FET source to amp negative
        * Capacitor from FET gate to amp negative
        * Amp output to amp gate
        * 10k 10nF
    * [x] Use higher-voltage supply for inamp circuits again to handle common-mode without saturating
        * Without this, TC and RTD amps read low and high-gain voltage inputs saturate well within intended 0-2.5V range
        * +/-12V split rail should do the trick
    * [x] Put supply voltage on ADJ/EN pin of LDOs
        * Previous revs' 4-20mA current limiter LDOs were functioning due to a coincidental hardware bug in the LDOs that caused them to latch enabled during board startup
        * Intended behavior of the LDO chip is to be powered down when ADJ/EN is shorted to ground
        * LDO targets ADJ pin as output voltage if ADJ voltage is > enable threshold (around 1.5V)
        * Bodge-wire testing confirms that putting 12V on the ADJ pin for the 12V LDO produces the intended behavior (pass-through with short-circuit protection)
    * [x] Remove LDO output caps & add 0.1uF input caps
        * Limit inrush to avoid over-current trip during board startup
    * [x] Add 1.024V on ref pin for high-gain voltage inputs to allow measuring with symmetric noise near 0V
    * [x] Add one power-on indicator LED back in
    * [x] Fix labeling of gain in schematic for 660x channel
    * [x] Update 3.3V zener to PN with smaller footprint
    * [x] Use back-to-back zeners for filter input to handle negative rail saturation
    * [x] Replace OPA333 with OPA196 for filters & use +/-12V split supply to get full range of 0-2.5V output
    * [x] Add -12V rail for inamp biasing
        * TI application note SLVAE10 fig 3 shows use of TPS560430 as inverting buck-boost
        * https://www.ti.com/lit/an/slvae10/slvae10.pdf
    * [x] Remove inamp from 4-20mA and G<=1 circuits in favor of overvoltage protection in filter circuits
    * [x] Remove PWM I/O logic buffers in favor of resistor-diode overvoltage protection & current-limiting
        * Buffers pull too much current & produce ground plane noise 
    * [x] Remove 5V converter that is no longer needed for anything 
    * [x] Remove extra mounting holes that will not be needed with an extrusion enclosure 
    * Prep layout for aluminum extrusion enclosure
        * https://www.protocase.com/products/electronic-enclosures/aluminum.php
        * [x] Move components back from board edge (min 0.64" clearance each side to tall parts, 0.2" to short parts & traces)
        * [x] Place remaining horizontal connectors on ends for panel access, 0.064" overhang for front/back panels
        * [x] Pack lever-wire connectors closer together now that the dimensions are confirmed
    * [x] Replace eth connector with one that is smaller and cheaper 
    * [x] Add enclosure
        * [x] Template
        * [x] Cutouts
        * [x] Silkscreen labels

### Changed

* Improved error handling and formatting in `deimos::controller`

## 2025-08-25 deimos 0.11.0, deimos_shared 0.5.0, Deimos DAQ Rev 5.0.0 hardware and firmware

### Added

* Add deimos_daq_rev5 schematic, layout, fab files, and firmware
    * Adds active analog filters, 2x buffered analog outputs, and more raw voltage inputs
* Add deimos_daq_rev5 interface to deimos_shared
* Add deimos_daq_rev5 peripheral implementation and calcs to deimos::peripheral

### Removed

* Remove deimos_gui

## 2025-06-28 deimos 0.10.2

### Changed

* Do not exit control loop immediately on transmit error
    * Instead, allow peripherals or controller to register loss of contact & follow established loss of contact procedure
    * This allows the control loop to bridge brief outages during DHCP IP address lease renewal

### Added

* Add ltspice models of several sizing options for zero-ripple Sallen-Key filters

## 2025-06-25 analog_i_rev4 firmware 0.4.0, deimos 0.10.1

### Changed

* Firmware
    * Update internal samplerate to 33kHz to restore timing margin that was lost to fractional delay filters
    * Add accumulated sampling time per comm cycle to cycle timing margin metric
* Software
    * Restore DataFrameDispatcher to top level public API
    * Remove conditional compilation flags from readme example

## 2025-06-21 analog_i_rev4 firmware 0.3.0

### Added

* Implement fractional delay FIR filters on scanned ADC samples to produce synthetic simultaneous sampling

## 2025-06-21 deimos 0.10.0, deimos_gui 0.1.1

### Changed

* Refactor to eliminate all conditional compilation features from control program
  * All features now enabled by default
* Remove polars dep due to excessive build time
* Refactor dataframe dispatcher module to use a lightweight internal dataframe target instead of a polars dataframe
* Update gui dep on control program to not reference features that no longer exist

### Added

## 2025-06-21 analog_i_rev4 firmware 0.2.0

### Added

* Add second (butter1) filter bank for low reporting rate to Sampler struct
* Add record of target cutoff ratio to Sampler struct
* Use second butter1 filter bank if target cutoff ratio is below stable range for nominal butter2 filter bank
  * This will activate below a reporting rate of 40Hz, allowing proper (though less performant) filtering at the very low end of viable reporting rate
  * Minimum tabulated cutoff ratio for the butter1 filter extends to a reporting rate of 4Hz, just below the system timing minimum freq of 5Hz
* Incidentally add SVG version of logo

## 2025-05-06 deimos 0.9.0, deimos_gui 0.1.0

### Added

* !Add bound on Debug for Calc and Peripheral to support use as part of state objects in iced gui
* Extract determination of calc eval order to `Orchestrator::eval_order()` and include evaluation depth
* Add read-only access to orchestrator via controller
* Add `all` feature
* Add `basic.rs` example

## 2025-05-03 deimos 0.8.1

Edits to prep for implementation of a calc node editor GUI.

### Added

* impl Clone for `Box<dyn Calc>` and `Box<dyn Peripheral>` by sending for a roundtrip loop through serde_json
  * Supports construction from prototype in GUI editor
* Add `kind` methods with default implementation to `Calc` and `Peripheral` to retrieve type name
* Add more methods for immutable access to calcs and peripherals via `Controller`
* Add `PeripheralProto` trait for prototyping `Peripheral` like `Calc`

### Changed

* Improve validation of `Sequence`
* Add non-empty default for `SequenceMachine`
* Derive `Default` on existing `Peripheral` types to allow blanket impl of `PeripheralProto`

## 2025-03-23 deimos 0.8.0

Implement `SequenceMachine` calc, which provides arbitrary lookup-table state machines in order to support
user-defined scheduling and operational logic.

### Changed

* !Make `ser` a default feature
* Make serde_json part of `ser` feature
* Update `multi_daq` example
  * Include more hardware units
  * Include an example `SequenceMachine` usage
  * Use the examples folder as the op folder
  * Make `ser` a required dep to handle loading `SequenceMachine` from disk

### Added

* Add `calc::sequence_machine` module with `SequenceMachine` and related types and functionality.

## 2025-02-23 deimos 0.7.0

Place functionality not required to run the base control program behind feature flags,
including serialization, user channels, and manipulation of thread priority and core affinity.
This reduces the base set of deps to 21, only 8 of which are not either proc macros or build deps.

### Changed

* !Roll forward to 2024 edition
* !Eliminate default features
* !Put serialization behind a feature flag
* !Put sideloading thread channels behind a feature flag
* !Put thread priority and core affinity behind a feature flag
* !Rename `SuperSocket` trait and types to `Socket`
* Reduce saved intermediate calcs in standard calcs for AnalogIRev{3,4}
* Include all features in docs

## 2025-02-22 Hardware - Analog I Rev 4.0.2

### Changed

* Replace input comparators with SN74LV Schmitt trigger logic buffers
    * Adds about 0.5V hysteresis to resolve jitter & eliminates exposure of 1V024 ref to noise from digital signals

## 2025-02-22 deimos 0.6.2, deimos_shared 0.4.0

### Changed

* !Remove duty cycle measurement from Analog I Rev4 firmware, packet format, and calcs
    * Despite deconflicting the duty cycle measurement to a different compare-and-capture and its own pin, configuring TIM4's second CCMR for duty cycle measurement causes both CCMR1 and CCMR2 to fail to trigger
    * This is the only remaining timer module with a second pin or compatible second compare-and-capture available, so duty cycle measurement will not be available on this unit
* Relicense under MIT/Apache-2.0 from 0BSD/Apache-2.0
* Update readme to be more concise

## 2025-02-09 deimos 0.6.1

### Added

* Add methods for parsing and emitting configuration packets to Peripheral
    * Default impl matches existing system, but allows future peripherals with additional config fields

## 2025-02-05 deimos 0.6.0

### Added

* Add `DataFrameDispatcher` for writing data to in-memory dataframe
* Add `Msg::Packet(Vec<u8>)` variant of user channel message to enable generic packetized message-passing
* !Add `terminate` method to `Dispatcher` and `Calc` traits and `Orchestrator` struct
    * To be called when the controller terminates, returning dispatchers to their pre-init state for reuse

### Changed

* !Rename `Panic` variant of `Overflow` to `Error`
    * Dispatchers can return an error on consuming values; this provides more flexibility in future error handling
* !Rename `initialize` method of `Dispatcher` trait to `init`
* !Rename `calcs` module to `calc`
* !Rename `peripherals` module to `peripheral`
* !Move orchestrator module under `calcs` and export 
* Make large const arrays static to avoid inlining excessively large data

## 2025-02-04 deimos 0.5.1

### Added

* Implement user channels
    * Bidirectional multiple-producer, multiple-consumer buffering message pipes
    * Passed to appendages with context during init
* Add sideloading example that uses user_ctx and user_channels fields to bypass nominal flow of information

## 2025-02-02 Hardware - Analog I Rev 4.0.1

### Changed - Hardware - Analog I Rev 4.0.1

* Replace input comparators with TLV3201s with 1M input pulldown to resolve inadequate drive strength
    * Non-inverting hysteresis-free configuration
* Move screw terminal inward and place silkscreen terminal labels on the outside
* Slightly widen board to make room for labels
* Update 3 pin screw terminal footprint for more accurate courtyard
* Update silkscreen labels to orient outward or toward the side opposite the power/eth plugs

## 2025-02-02 deimos 0.5.0, deimos_shared 0.3.0, firmware analog_i_rev4 0.1.0

### Added - deimos

* Add AnalogIRev4 peripheral implementation

### Changed - deimos

* Rename `analog_i_rev3` example to `multi_daq` and add an AnalogIRev4
* Specify mode explicitly in config packet
* Start clock for binding just before transmission & remove 1ms pad
* Update function signature for SuperSocket::update_map to be fallible
    * This provides a means to handle errors for duplicate addresses
* Update UDP and unix socket implementations to check for duplicate addresses when building address table

### Added - deimos_shared

* Add AnalogIRev4 packet format

### Changed - deimos_shared

* Mark `Mode` enum non-exhaustive

### Added - firmware

* Add analog_i_rev4 firmware
    * Compared to rev3, includes use of second compare-and-capture on TIM4/FREQ0 input to extract duty cycle

## 2025-02-01 deimos 0.4.0, deimos_shared 0.2.0

### Added - deimos

* Add implementation of SuperSocket for unix datagram socket
* Add non-exhaustive `ControllerCtx` context struct to store growing number of settings
* Add non-exhaustive `Termination` enum for planned termination criteria
* Add non-exhaustive `LossOfContactPolicy` enum for choosing reconnect behavior
* Add `ipc_plugin` example demonstrating use of peripheral plugins, a software-defined peripheral state machine, and use of unix socket for communication with a software-defined peripheral
* Add `dispatcher::fmt_time` method to reduce repeated code for fixed-width UTC formatting
* Add `calcs` and `peripherals` modules relocated from `deimos_shared`
* Add `scripts` folder relocated from `deimos_shared`
* Add github actions workflow that runs IPC example for end-to-end smoketest

### Changed - deimos

* Update function signatures for controller methods to use context instead of individual arguments
* Update function signatures for plugins to be compatible with object safety
* Update control loop to accept and use plugins
* Update SuperSocket init to take context
* Update Dispatcher init to take context
* Update Orchestrator and Calc init to take context
* Make runtime internal state (`ControllerState`, `PeripheralState`, `TimingPid`) pub(crate) as they are not usable outside the specifics of the controller internals
* Update docs

### Changed - deimos_shared

* Remove unnecessary methods from `Peripheral` trait & implementations
* Remove `std` feature and related deps
* Move stdlib portion of library (`Calc` and `Peripheral` traits and impls, as well as `PluginFn` and `PluginMap`) to `deimos`
    * deimos_shared is now purely the `no-std` shared library
* Move `scripts` folder to `deimos`
* Update docs

### Changed - firmware

* Update flash.py and flash.sh to accept model name and use it for the path to the appropriate firmware folder

## 2025-01-26 deimos 0.3.0, deimos_shared 0.1.3

### Added - deimos

* Add socket module with SuperSocket trait and related types
* Add implementation of SuperSocket for UDP

### Changed - deimos

* Update controller to use new socket interface

### Changed - deimos_shared

* Update module docstrings

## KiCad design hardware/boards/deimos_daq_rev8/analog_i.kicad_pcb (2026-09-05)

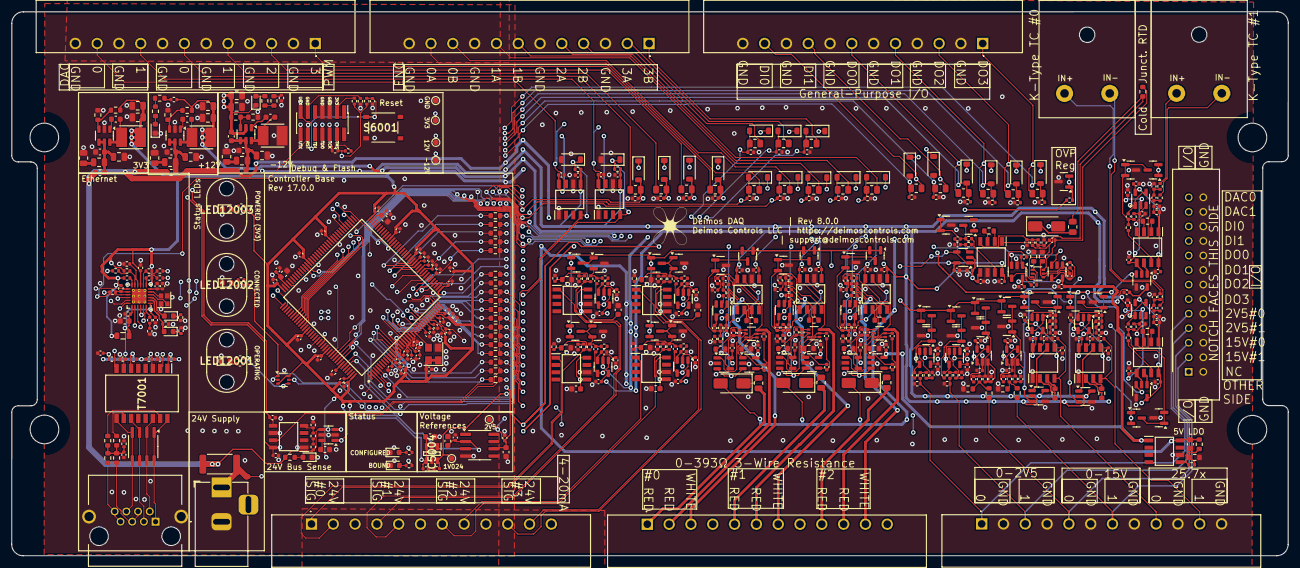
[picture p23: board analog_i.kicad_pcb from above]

Board: 4 copper layers, 223.0 x 95.0 mm, 582 parts (0 on the bottom side), 312 nets.

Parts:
-1001: logo_minimal_25p4_by_20p3_mm; logo_minimal_12p7_by_10p9_mm
C3003, C10001, C10005, C11002, C11005, C14002, C14005, C14006, C28001, C30001, C32001, C34001: 0.1uF 50V 0603; C_0603_1608Metric
C4001, C4003, C5001, C5003, C9001, C9003, C13001, C13003, C15001, C15003, C17001, C17003: 2.2uF; C_0402_1005Metric
C4002, C5002, C9002, C13002, C15002, C17002: 1uF; C_0402_1005Metric
C4004, C4005, C4007, C4010, C5004, C5007, C5008, C5009, C5010, C6021, C6022, C6024, C6026, C6027, C6028, C6029, C6030, C6031, C6032, C6033, C6034, C6036, C6037, C6038, C6039, C6041, C6043, C6048, C6050, C7005, C7006, C7007, C7008, C7010, C7011, C8002, C8005, C9004, C9005, C13004, C13007, C13010, C15004, C15008, C15009, C16001, C17004, C17007, C17008, C17009, C17010, C18002, C19003, C19004, C21003, C21004, C23001, C24001, C24004, C26001, C27003, C27004, C29003, C29004, C31003, C31004, C33003, C33004, C35003, C35004, C36001, C36002, C37003, C37004, C38001, C38002, C39003, C39004, C41003, C41004, C43003, C43004, C45003, C45004, C47003, C47004, C53001, C53002, C54001, C54002: 0.1uF; C_0402_1005Metric
C4006, C4008, C6023, C6025, C9007, C9008, C11001, C14001, C18001, C22001, C23002, C23003, C26002, C26003: 10nF; C_0402_1005Metric
C5012, C6035, C6040, C6049, C6051, C7009: 10uF; C_0603_1608Metric
C6001, C6002, C6003, C6004, C6005, C6006, C6007, C6008, C6009, C6010, C6011, C6012, C6013, C6016, C6017, C6018, C6019, C6020, C7004: 1uF 0402; C_0402_1005Metric
C7003: 470pF 0402; C_0402_1005Metric
C7012: 4.7nF; C_0402_1005Metric
C8001: 0.1uF 0603; C_0603_1608Metric
C10002, C10003, C10004, C11003, C11004, C11007, C14003, C14004, C14008: 10uF 50V 0805; C_0805_2012Metric
C10006, C11006, C14007: 2.2uF 50V 0805; C_0805_2012Metric
C15005, C15007, C17005, C17006, C19001, C19002, C21001, C21002, C24002, C24003, C27001, C27002, C29001, C29002, C31001, C31002, C33001, C33002, C35001, C35002, C37001, C37002, C39001, C39002, C41001, C41002, C43001, C43002, C45001, C45002, C47001, C47002: 10nF C0G 5%; C_0402_1005Metric
D4001, D5001, D13001, D17001: D_Schottky; D_SMA
D6001, D6002, D6003, D6004, D7001, D7002, D12001, D12002, D12003, D12004: Purple LED; LED_0603_1608Metric
D7003: CDNBS08-SLVU2.8-4; SOIC-8_3.9x4.9mm_P1.27mm
D48001, D49001, D50001, D51001, D52001, D53002, D54002, D55002, D56001, D57001, D58001, D59001, D60001, D61001, D62001, D63001, D64001, D65001, D66001, D67001: B5819W SL; D_SOD-123
FB7001: GZ2012D601TF; L_0805_2012Metric
H2001, H2002, H3001, H3002: MountingHole_for_10-32; MountingHole_5mm
IC3002, IC17004, IC20001, IC24001, IC28001: BD42540FJ-CE2; SOIC127P600X175-8N
IC4001, IC5001, IC8001, IC9001, IC13001, IC15001, IC17001, IC36001, IC38001, IC53001, IC54001: INA826AIDR; SOIC127P600X175-8N
IC4002, IC4003, IC5002, IC5003, IC13002, IC13003, IC17002, IC17003: TLV333IDBVR; SOT-23-5
IC5004: REF35102QDBVR; SOT95P280X145-6N
IC6001: STM32H743ZIT6; QFP50P2200X2200X160-144N
IC10001, IC11001, IC14001: TPS560430XDBVR; SOT-23-6
J3001, J3002, J3003, J3004, J3005, J3006: WJ15EDGRM-3.81-12P
J3007: XG4C-2631; SHDR26W70P254_2X13_4030X820X900P
J6001: Conn_02x07_Odd_Even; PinHeader_2x07_P1.27mm_Vertical_SMD
J8001: Barrel_Jack PJ-202BH; BarrelJack_Horizontal
J9001, J15001: AM-K-PCB
J13001: RCH_RC01133; RCHRC01133
L10001: 12uH FNR4030S120MT; INDPM4040X300N
L10002, L11002, L14002: 220nH 0603; L_0603_1608Metric
L11001, L14001: 33uH FNR4020S330MT; INDPM4040X300N
LED12001, LED12002, LED12003: SMFLP10.0; SMFLP100
Q15001, Q15002, Q17001, Q17002, Q19001, Q19002, Q21001, Q21002, Q24001, Q24002, Q27001, Q27002, Q29001, Q29002, Q31001, Q31002, Q33001, Q33002, Q35001, Q35002, Q37001, Q37002, Q39001, Q39002, Q41001, Q41002, Q43001, Q43002, Q45001, Q45002, Q47001, Q47002: MMBFJ113; SOT-23
R3001: PTS060301B100RP100; R_0603_1608Metric
R3002, R11004, R12001, R14005: 243k 0603; R_0603_1608Metric
R3003, R17001, R17007, R19001, R19002, R37001, R37002, R39001, R39002: 10k 1%; R_0402_1005Metric
R3004, R10002: 51k 0603; R_0603_1608Metric
R3005, R21001, R21002, R24001, R24002, R27001, R27002, R29001, R29002, R31001, R31002, R33001, R33002, R35001, R35002, R41001, R41002, R43001, R43002, R45001, R45002, R47001, R47002, R53001, R54001: 3.3k 1%; R_0402_1005Metric
R4001, R4007, R9004, R9006, R23001, R23002, R26001, R26002: 10k 1%; C_0402_1005Metric
R4002, R5002, R9005, R13002, R15005, R17002, R36001, R38001, R40002, R42002: RNCF0603TKY2K00 2k 0.01% 5ppm/C; R_0603_1608Metric
R4003, R5003, R13003, R17003: 300; R_0805_2012Metric
R4004, R4005, R5004, R5005, R13004, R13005, R17004, R17005: 10; C_0402_1005Metric
R4006, R4009, R5006, R5009, R13006, R13009, R17006, R17009, R40001, R42001: RNCF0603TKW10K0 10k 0.01% 5ppm/C; R_0603_1608Metric
R6001, R6002, R6003, R6004, R6005, R6006, R6007, R6008, R6009, R6010, R6011, R6012, R6013, R6016, R6017, R6018, R6019, R6020: 10R 0603; R_0603_1608Metric
R6021, R6022, R6028, R6029, R6030, R7002, R7004, R7006, R7009, R7010, R7012, R7019, R8006, R8007, R12002, R12005: 10k; R_0402_1005Metric
R6024, R12008, R12009, R12010, R12011, R12012, R12013, R13007: 100R 0402; R_0402_1005Metric
R6025, R6026: 1k; R_0402_1005Metric
R7001, R7003, R7005, R7007: 33R; R_0402_1005Metric
R7008, R7015, R8005: 1.5k; R_0402_1005Metric
R7011, R7013, R7016, R7018: 49.9; R_0402_1005Metric
R7014: 12k; R_0402_1005Metric
R7017: 100R; R_0402_1005Metric
R7020, R7021, R7022, R7023: 75; R_0603_1608Metric
R7024, R9003, R15003, R28001, R30001, R32001, R34001, R36002, R38002, R44001, R46001, R48002, R49002, R50002, R51002, R52002, R53003, R54003, R55001, R55004, R56001, R57001, R58001, R59001, R60001, R61001, R64001, R65002, R66002: 1M; R_0402_1005Metric
R8004: MRF6432(2512)LR006FTS 0.006 1%; R_2512_6332Metric
R9001, R9002, R15001, R15002: 10; R_0402_1005Metric
R10001, R11005, R12003, R12004, R12006, R12007, R14004: 22.1k 0603; R_0603_1608Metric
R10003, R11003, R14003: 1R 0805; R_0805_2012Metric
R11001, R14001, R18001, R22001: 200R; R_0402_1005Metric
R11002, R14002, R18002, R22002: RNCF0603TKY75R0 75R 0.01% 5ppm/C; R_0603_1608Metric
R15004, R15006: 100k 1%; R_0402_1005Metric
R48001, R49001, R50001, R51001, R52001, R53002, R54002, R55003, R65001, R66001: 22k; R_0805_2012Metric
R55002, R56002, R57002, R58002, R59002, R60002, R61002, R64002: 49.9; R_0805_2012Metric
S6001: TS-1187A-B-A-B; TS1187ABAB
T7001: H1102NLT; SOIC127P940X622-16N
TP7001, TP7002: TestPoint_+12V; TestPoint_Pad_D1.0mm
TP7003: TestPoint_+2V5; TestPoint_Pad_D1.0mm
TP7004: TestPoint_+3V3; TestPoint_Pad_D1.0mm
TP7005: TestPoint_+1V024; TestPoint_Pad_D1.0mm
TP8002: TestPoint_GND_1; TestPoint_Pad_D1.0mm
U3001: ATL431BQDBZR; SOT-23
U4001, U5001, U12001, U13001, U17001: NTJD4001NT1G; SOT-363_SC-70-6
U6002: ADR4525; SOIC-8_3.9x4.9mm_P1.27mm
U7001: LAN8742A; VQFN-24-1EP_4x4mm_P0.5mm_EP2.5x2.5mm_ThermalVias
U8001: INA181A2; SOT-23-6
U15001, U16001, U17002, U18001, U19001, U21001, U24001, U27001, U29001, U31001, U33001, U35001, U36001, U37001, U38001, U39001, U41001, U43001, U45001, U47001: OPA196xDBV; SOT-23-5
Y6001: SiT1602BI-21-33S-48.000000; Crystal_SMD_3225-4Pin_3.2x2.5mm
Y7001: NX2016SA-25.000M-STD-CZS-1; Crystal_SMD_2016-4Pin_2.0x1.6mm

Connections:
2V5_OVP: Q15001.1 (D), Q15001.2 (S), Q17001.1 (D), Q17001.2 (S), Q19001.1 (D), Q19001.2 (S), Q21001.1 (D), Q21001.2 (S), Q24001.1 (D), Q24001.2 (S), Q27001.1 (D), Q27001.2 (S), Q29001.1 (D), Q29001.2 (S), Q31001.1 (D), Q31001.2 (S), Q33001.1 (D), Q33001.2 (S), Q35001.1 (D), Q35001.2 (S), Q37001.1 (D), Q37001.2 (S), Q39001.1 (D), Q39001.2 (S), Q41001.1 (D), Q41001.2 (S), Q43001.1 (D), Q43001.2 (S), Q45001.1 (D), Q45001.2 (S), Q47001.1 (D), Q47001.2 (S), R3005.1, U3001.1 (K), U3001.2 (REF)
+1V024: C5008.1, IC5004.6 (VREF), TP7005.1, U16001.3 (+), U18001.3 (+), U36001.3 (+), U38001.3 (+)
+2V5: C6023.2, C6024.2, C6050.2, C6051.2, IC4002.3 (+IN), IC4003.3 (+IN), IC5002.3 (+IN), IC5003.3 (+IN), IC6001.32 (VREF+), IC13002.3 (+IN), IC13003.3 (+IN), IC17002.3 (+IN), IC17003.3 (+IN), TP7003.1, U6002.6 (OUT)
+3V3: C5009.2, C5012.2, C6021.2, C6022.2, C6025.2, C6026.2, C6028.2, C6029.2, C6030.2, C6031.2, C6032.2, C6033.2, C6036.2, C6037.2, C6038.2, C6039.2, C6043.2, C6048.2, C6049.2, C7005.2, C8001.1, C10003.1, C10006.1, D4001.2 (A), D5001.2 (A), D13001.2 (A), D17001.2 (A), D48001.1 (K), D49001.1 (K), D50001.1 (K), D51001.1 (K), D52001.1 (K), D53002.1 (K), D54002.1 (K), D55002.1 (K), D58001.1 (K), D59001.1 (K), D60001.1 (K), D61001.1 (K), D62001.1 (K), D63001.1 (K), D64001.1 (K), D65001.1 (K), D66001.1 (K), D67001.1 (K), FB7001.1, IC5004.3 (EN), IC5004.4 (VIN), IC6001.17 (VDD_1), IC6001.30 (VDD_2), IC6001.33 (VDDA), IC6001.39 (VDD_3), IC6001.52 (VDD_4), IC6001.62 (VDD_5), IC6001.72 (VDD_6), IC6001.84 (VDD_7), IC6001.95 (VDD33USB), IC6001.108 (VDD_8), IC6001.121 (VDD_9), IC6001.131 (VDD_10), IC6001.144 (VDD_11), L10001.1, R3005.2, R6021.1, R6028.1, R6029.2, R6030.2, R7002.1, R7004.1, R7006.1, R7008.2, R7009.1, R10002.1, R12008.1, R13007.1, TP7004.1, U6002.2 (IN), U7001.9 (VDDIO), U8001.6 (V+), U12001.3 (D2), U12001.6 (D1), Y6001.1 (OE/~ST/NC), Y6001.4 (VDD)
+5V: C4007.1, C4010.1, C5007.1, C5010.1, C13007.1, C13010.1, C17007.1, C17010.1, IC3002.1 (VO), IC4002.5 (V+), IC4003.5 (V+), IC5002.5 (V+), IC5003.5 (V+), IC13002.5 (V+), IC13003.5 (V+), IC17002.5 (V+), IC17003.5 (V+)
+12V: C4004.1, C5004.1, C8005.2, C9004.1, C11006.1, C11007.1, C13004.1, C15004.1, C15008.2, C17004.1, C17008.2, C19003.2, C21003.2, C24001.2, C27003.2, C29003.2, C31003.2, C33003.2, C35003.2, C36001.2, C37003.2, C38001.2, C39003.2, C41003.2, C43003.2, C45003.2, C47003.2, C53001.2, C54001.2, IC4001.8 (+VS), IC5001.8 (+VS), IC8001.8 (+VS), IC9001.8 (+VS), IC13001.8 (+VS), IC15001.8 (+VS), IC17001.8 (+VS), IC36001.8 (+VS), IC38001.8 (+VS), IC53001.8 (+VS), IC54001.8 (+VS), L11001.1, R11004.1, R12005.2, TP7001.1, U15001.5 (V+), U16001.5 (V+), U17002.5 (V+), U18001.5 (V+), U19001.5 (V+), U21001.5 (V+), U24001.5 (V+), U27001.5 (V+), U29001.5 (V+), U31001.5 (V+), U33001.5 (V+), U35001.5 (V+), U36001.5 (V+), U37001.5 (V+), U38001.5 (V+), U39001.5 (V+), U41001.5 (V+), U43001.5 (V+), U45001.5 (V+), U47001.5 (V+)
+24V: C3003.2, C28001.2, C30001.2, C32001.2, C34001.2, IC3002.8 (VCC), IC17004.5 (ADJ_/_EN), IC17004.8 (VCC), IC20001.5 (ADJ_/_EN), IC20001.8 (VCC), IC24001.5 (ADJ_/_EN), IC24001.8 (VCC), IC28001.5 (ADJ_/_EN), IC28001.8 (VCC), L10002.2, L11002.2, L14002.2, R3002.2, R8004.1, R8006.1, R12001.2, U8001.4 (-)
-12V: C4005.1, C8002.2, C9005.1, C14005.1, C14007.1, C14008.1, C15009.2, C16001.2, C17009.2, C18002.2, C19004.2, C21004.2, C23001.1, C24004.2, C26001.1, C27004.2, C29004.2, C31004.2, C33004.2, C35004.2, C36002.2, C37004.2, C38002.2, C39004.2, C41004.2, C43004.2, C45004.2, C47004.2, C53002.2, C54002.2, D12002.1 (K), IC4001.5 (-VS), IC5001.5 (-VS), IC8001.5 (-VS), IC9001.5 (-VS), IC13001.5 (-VS), IC14001.2 (GND), IC15001.5 (-VS), IC17001.5 (-VS), IC36001.5 (-VS), IC38001.5 (-VS), IC53001.5 (-VS), IC54001.5 (-VS), R14004.2, R53001.1, R54001.1, TP7002.1, U15001.2 (V-), U16001.2 (V-), U17002.2 (V-), U18001.2 (V-), U19001.2 (V-), U21001.2 (V-), U24001.2 (V-), U27001.2 (V-), U29001.2 (V-), U31001.2 (V-), U33001.2 (V-), U35001.2 (V-), U36001.2 (V-), U37001.2 (V-), U38001.2 (V-), U39001.2 (V-), U41001.2 (V-), U43001.2 (V-), U45001.2 (V-), U47001.2 (V-)
/analog_frontend/2p5V_0: J3003.1, J3007.9, R46001.1, R47001.1
/analog_frontend/2p5V_1: J3003.3, J3007.7, R44001.1, R45001.1
/analog_frontend/4-20mA Frontend1/+24_EXC: IC20001.1 (VO), J3002.5
/analog_frontend/4-20mA Frontend1/SIGNAL: J3002.4, R14001.2, R14002.2, R32001.1, R33001.1
/analog_frontend/4-20mA Frontend2/+24_EXC: IC24001.1 (VO), J3002.8
/analog_frontend/4-20mA Frontend2/SIGNAL: J3002.7, R18001.2, R18002.2, R30001.1, R31001.1
/analog_frontend/4-20mA Frontend3/+24_EXC: IC28001.1 (VO), J3002.11
/analog_frontend/4-20mA Frontend3/SIGNAL: J3002.10, R22001.2, R22002.2, R28001.1, R29001.1
/analog_frontend/4-20mA Frontend/+24_EXC: IC17004.1 (VO), J3002.2
/analog_frontend/4-20mA Frontend/SIGNAL: J3002.1, R11001.2, R11002.2, R34001.1, R35001.1
/analog_frontend/15V_0: J3003.5, J3007.5, R42001.2
/analog_frontend/15V_1: J3003.7, J3007.3, R40001.2
/analog_frontend/25p7x_0: IC38001.4 (+IN), J3003.9, R38002.1
/analog_frontend/25p7x_1: IC36001.4 (+IN), J3003.11, R36002.1
/analog_frontend/AIN2: C15007.2, R6003.1, U15001.1, U15001.4 (-)
/analog_frontend/AIN3: C35002.2, R6007.1, U35001.1, U35001.4 (-)
/analog_frontend/AIN4: C33002.2, R6008.1, U33001.1, U33001.4 (-)
/analog_frontend/AIN5: C31002.2, R6004.1, U31001.1, U31001.4 (-)
/analog_frontend/AIN6: C29002.2, R6005.1, U29001.1, U29001.4 (-)
/analog_frontend/AIN7: C21002.2, R6006.1, U21001.1, U21001.4 (-)
/analog_frontend/AIN8: C24003.2, R6009.1, U24001.1, U24001.4 (-)
/analog_frontend/AIN9: C27002.2, R6010.1, U27001.1, U27001.4 (-)
/analog_frontend/AIN10: C17006.2, R6011.1, U17002.1, U17002.4 (-)
/analog_frontend/AIN11: C19002.2, R6012.1, U19001.1, U19001.4 (-)
/analog_frontend/AIN12: C47002.2, R6013.1, U47001.1, U47001.4 (-)
/analog_frontend/AIN13_DAC0: D56001.1 (K), IC6001.40 (PA4), IC53001.4 (+IN), R53001.2
/analog_frontend/AIN14_DAC1: D57001.1 (K), IC6001.41 (PA5), IC54001.4 (+IN), R54001.2
/analog_frontend/AIN15: C45002.2, R6016.1, U45001.1, U45001.4 (-)
/analog_frontend/AIN16: C43002.2, R6017.1, U43001.1, U43001.4 (-)
/analog_frontend/AIN17: C41002.2, R6018.1, U41001.1, U41001.4 (-)
/analog_frontend/AIN18: C39002.2, R6019.1, U39001.1, U39001.4 (-)
/analog_frontend/AIN19: C37002.2, R6020.1, U37001.1, U37001.4 (-)
/analog_frontend/DAC0: IC53001.7 (VOUT), J3005.11, J3007.25
/analog_frontend/DAC1: IC54001.7 (VOUT), J3005.9, J3007.23
/analog_frontend/DI0: D65001.2 (A), IC6001.114 (PD0), R65001.2, R65002.1
/analog_frontend/DI0_CONN: J3006.11, J3007.21, R65001.1
/analog_frontend/DI1: D66001.2 (A), IC6001.115 (PD1), R66001.2, R66002.1
/analog_frontend/DI1_CONN: J3006.9, J3007.19, R66001.1
/analog_frontend/DO0: D67001.2 (A), IC6001.116 (PD2), R64001.1, R64002.1
/analog_frontend/DO0_CONN: J3006.7, J3007.17, R64002.2
/analog_frontend/DO1: D62001.2 (A), IC6001.117 (PD3), R59001.1, R59002.1
/analog_frontend/DO1_CONN: J3006.5, J3007.15, R59002.2
/analog_frontend/DO2: D63001.2 (A), IC6001.118 (PD4), R60001.1, R60002.1
/analog_frontend/DO2_CONN: J3006.3, J3007.13, R60002.2
/analog_frontend/DO3: D64001.2 (A), IC6001.119 (PD5), R61001.1, R61002.1
/analog_frontend/DO3_CONN: J3006.1, J3007.11, R61002.2
/analog_frontend/ENCODER0_A: D48001.2 (A), IC6001.60 (PE9), R48001.2, R48002.1
/analog_frontend/ENCODER0_B: D49001.2 (A), IC6001.64 (PE11), R49001.2, R49002.1
/analog_frontend/ENCODER1_A: D50001.2 (A), IC6001.96 (PC6), R50001.2, R50002.1
/analog_frontend/ENCODER1_B: D51001.2 (A), IC6001.97 (PC7), R51001.2, R51002.1
/analog_frontend/ENCODER2_A: D52001.2 (A), IC6001.136 (PB6), R52001.2, R52002.1
/analog_frontend/ENCODER2_B: D53002.2 (A), IC6001.137 (PB7), R53002.2, R53003.1
/analog_frontend/ENCODER3_A: D54002.2 (A), IC6001.134 (PB4), R54002.2, R54003.1
/analog_frontend/ENCODER3_B: D55002.2 (A), IC6001.135 (PB5), R55003.2, R55004.1
/analog_frontend/K-Type TC Amp1/Signal+: C15001.1, C15002.1, IC15001.4 (+IN), R15001.2
/analog_frontend/K-Type TC Amp1/Signal-: C15002.2, C15003.1, IC15001.1 (-IN1), R15002.1, R15003.1
/analog_frontend/K-Type TC Amp1/sallen_key_1kHz/VIN: IC15001.7 (VOUT), R19001.1
/analog_frontend/K-Type TC Amp/Signal+: C9001.1, C9002.1, IC9001.4 (+IN), R9001.2
/analog_frontend/K-Type TC Amp/Signal-: C9002.2, C9003.1, IC9001.1 (-IN1), R9002.1, R9003.1
/analog_frontend/K-Type TC Amp/sallen_key_1kHz/VIN: IC9001.7 (VOUT), R17001.1
/analog_frontend/PWM0: D58001.2 (A), IC6001.5 (PE6), R55001.1, R55002.1
/analog_frontend/PWM1: D59001.2 (A), IC6001.75 (PB14), R56001.1, R56002.1
/analog_frontend/PWM2: D60001.2 (A), IC6001.139 (PB8), R57001.1, R57002.1
/analog_frontend/PWM3: D61001.2 (A), IC6001.140 (PB9), R58001.1, R58002.1
/analog_frontend/RTD Amp1/R+: J3001.5, R13003.2
/analog_frontend/RTD Amp1/R-: J3001.6, R13004.2, U13001.3 (D2)
/analog_frontend/RTD Amp1/W-: J3001.7, R13005.2, U13001.6 (D1)
/analog_frontend/RTD Amp1/rtd_amp_inner/Signal+: C13001.2, C13002.1, IC13001.4 (+IN), R13004.1
/analog_frontend/RTD Amp1/rtd_amp_inner/Signal-: C13002.2, C13003.1, IC13001.1 (-IN1), R13005.1
/analog_frontend/RTD Amp1/rtd_amp_inner/Vout: IC13001.7 (VOUT), R24001.1
/analog_frontend/RTD Amp2/R+: J3001.9, R17003.2
/analog_frontend/RTD Amp2/R-: J3001.10, R17004.2, U17001.3 (D2)
/analog_frontend/RTD Amp2/W-: J3001.11, R17005.2, U17001.6 (D1)
/analog_frontend/RTD Amp2/rtd_amp_inner/Signal+: C17001.2, C17002.1, IC17001.4 (+IN), R17004.1
/analog_frontend/RTD Amp2/rtd_amp_inner/Signal-: C17002.2, C17003.1, IC17001.1 (-IN1), R17005.1
/analog_frontend/RTD Amp2/rtd_amp_inner/Vout: IC17001.7 (VOUT), R27001.1
/analog_frontend/RTD Amp/R+: J3001.1, R5003.2
/analog_frontend/RTD Amp/R-: J3001.2, R5004.2, U5001.3 (D2)
/analog_frontend/RTD Amp/W-: J3001.3, R5005.2, U5001.6 (D1)
/analog_frontend/RTD Amp/rtd_amp_inner/Signal+: C5001.2, C5002.1, IC5001.4 (+IN), R5004.1
/analog_frontend/RTD Amp/rtd_amp_inner/Signal-: C5002.2, C5003.1, IC5001.1 (-IN1), R5005.1
/analog_frontend/RTD Amp/rtd_amp_inner/Vout: IC5001.7 (VOUT), R21001.1
/analog_frontend/ain_0-15V_1/sallen_key_3kHz8/VIN: R40001.1, R40002.1, R41001.1
/analog_frontend/ain_0-15V_/sallen_key_3kHz8/VIN: R42001.1, R42002.1, R43001.1
/analog_frontend/ain_g25p7_1/sallen_key_1kHz2/VIN: IC36001.7 (VOUT), R37001.1
/analog_frontend/ain_g25p7_/sallen_key_1kHz2/VIN: IC38001.7 (VOUT), R39001.1
/analog_frontend/pwm_in_buf1/VIN: J3004.11, R48001.1
/analog_frontend/pwm_in_buf2/VIN: J3004.5, R52001.1
/analog_frontend/pwm_in_buf3/VIN: J3004.7, R51001.1
/analog_frontend/pwm_in_buf4/VIN: J3004.8, R50001.1
/analog_frontend/pwm_in_buf5/VIN: J3004.4, R53002.1
/analog_frontend/pwm_in_buf8/VIN: J3004.2, R54002.1
/analog_frontend/pwm_in_buf9/VIN: J3004.1, R55003.1
/analog_frontend/pwm_in_buf/VIN: J3004.10, R49001.1
/analog_frontend/pwm_out_buf1/VOUT: J3005.5, R56002.2
/analog_frontend/pwm_out_buf2/VOUT: J3005.3, R57002.2
/analog_frontend/pwm_out_buf3/VOUT: J3005.1, R58002.2
/analog_frontend/pwm_out_buf/VOUT: J3005.7, R55002.2
/analog_frontend/rtd_amp_inner1/250uA_SINK_1: R3001.1, R4005.2, U4001.6 (D1)
/analog_frontend/rtd_amp_inner1/250uA_SINK_2: R3001.2, R4003.2, R4004.2, U4001.3 (D2)
/analog_frontend/rtd_amp_inner1/Signal+: C4001.2, C4002.1, IC4001.4 (+IN), R4004.1
/analog_frontend/rtd_amp_inner1/Signal-: C4002.2, C4003.1, IC4001.1 (-IN1), R4005.1
/analog_frontend/rtd_amp_inner1/Vout: IC4001.7 (VOUT), R15004.2
/base/AIN0: R6001.1, U8001.1
/base/AIN1: IC8001.7 (VOUT), R6002.1
/base/Micro/AIN0_Filt: C6001.1, IC6001.13 (PF3), R6001.2
/base/Micro/AIN1_Filt: C6002.1, IC6001.14 (PF4), R6002.2
/base/Micro/AIN2_Filt: C6003.1, IC6001.15 (PF5), R6003.2
/base/Micro/AIN3_Filt: C6007.1, IC6001.18 (PF6), R6007.2
/base/Micro/AIN4_Filt: C6008.1, IC6001.19 (PF7), R6008.2
/base/Micro/AIN5_Filt: C6004.1, IC6001.20 (PF8), R6004.2
/base/Micro/AIN6_Filt: C6005.1, IC6001.21 (PF9), R6005.2
/base/Micro/AIN7_Filt: C6006.1, IC6001.22 (PF10), R6006.2
/base/Micro/AIN8_Filt: C6009.1, IC6001.26 (PC0), R6009.2
/base/Micro/AIN9_Filt: C6010.1, IC6001.28 (PC2_C), R6010.2
/base/Micro/AIN10_Filt: C6011.1, IC6001.29 (PC3_C), R6011.2
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

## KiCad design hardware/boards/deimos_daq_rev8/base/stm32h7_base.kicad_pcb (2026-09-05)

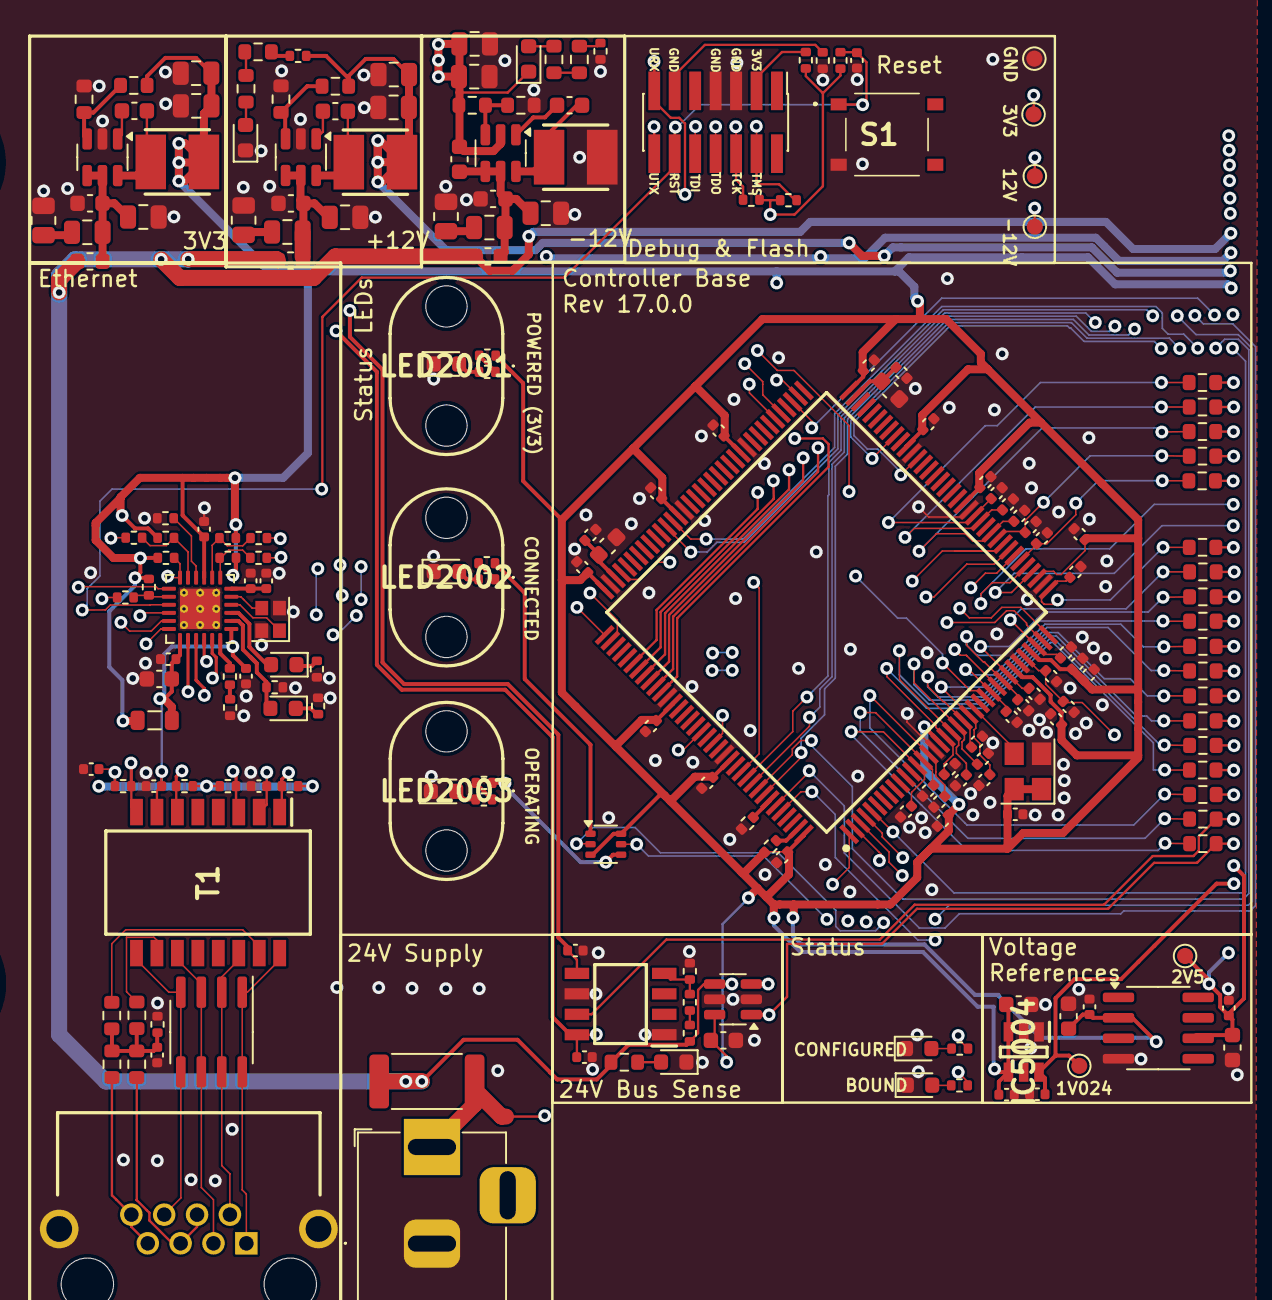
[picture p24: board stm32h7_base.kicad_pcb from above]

Board: 4 copper layers, 202 parts (0 on the bottom side), 117 nets.

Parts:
C9, C10, C23, C5002, C5004, C6003: 10uF; C_0603_1608Metric
C11, C12, C13, C14, C15, C17, C18, C19, C22, C24, C26, C28, C29, C30, C31, C32, C33, C34, C35, C36, C37, C38, C39, C40, C4004, C5001, C5003, C5005, C6001, C6002: 0.1uF; C_0402_1005Metric
C16: 4.7nF; C_0402_1005Metric
C25: 470pF 0402; C_0402_1005Metric
C27, C44, C45, C46, C47, C48, C49, C50, C51, C52, C53, C54, C55, C56, C59, C60, C61, C62, C63: 1uF 0402; C_0402_1005Metric
C42, C43: 10nF; C_0402_1005Metric
C4001: 0.1uF 0603; C_0603_1608Metric
C4002, C4008, C4011, C7003, C9001, C9002, C10005: 0.1uF 50V 0603; C_0603_1608Metric
C4006, C4007, C4010, C7001, C7002, C7004, C9004, C10001, C10002: 10uF 50V 0805; C_0805_2012Metric
C4009, C9003, C10006: 2.2uF 50V 0805; C_0805_2012Metric
D2, D6, D36, D37, D38, D39, D2001, D2003, D2004, D2005: Purple LED; LED_0603_1608Metric
D5: CDNBS08-SLVU2.8-4; SOIC-8_3.9x4.9mm_P1.27mm
FB1: GZ2012D601TF; L_0805_2012Metric
H1001, H1002: MountingHole_for_10-32; MountingHole_5mm
IC1: STM32H743ZIT6; QFP50P2200X2200X160-144N
IC4001, IC10001, IC10002: TPS560430XDBVR; SOT-23-6
IC5004: REF35102QDBVR; SOT95P280X145-6N
IC8001: INA826AIDR; SOIC127P600X175-8N
J4: Conn_02x07_Odd_Even; PinHeader_2x07_P1.27mm_Vertical_SMD
J3001: RCH_RC01133; RCHRC01133
J8001: Barrel_Jack PJ-202BH; BarrelJack_Horizontal
L4001, L9001: 33uH FNR4020S330MT; INDPM4040X300N
L4002, L8001, L9002: 220nH 0603; L_0603_1608Metric
L7001: 12uH FNR4030S120MT; INDPM4040X300N
LED2001, LED2002, LED2003: SMFLP10.0; SMFLP100
R1, R2, R3, R4, R6, R27, R28, R29, R30, R31, R33, R49, R2007, R2008, R8006, R8007: 10k; R_0402_1005Metric
R5, R50: 1k; R_0402_1005Metric
R8, R9, R10, R11, R22, R32, R35, R36, R37, R38, R39, R40, R41, R44, R45, R46, R51, R52: 10R 0603; R_0603_1608Metric
R13, R14, R15, R16: 49.9; R_0402_1005Metric
R17, R18, R19, R20: 75; R_0603_1608Metric
R21: 1M; R_0402_1005Metric
R23, R26, R47, R48: 33R; R_0402_1005Metric
R34, R56, R8005: 1.5k; R_0402_1005Metric
R54: 12k; R_0402_1005Metric
R57: 100R; R_0402_1005Metric
R58, R2001, R2002, R2004, R2011, R2012, R2013, R2014: 100R 0402; R_0402_1005Metric
R2003, R4002, R9001: 243k 0603; R_0603_1608Metric
R2005, R2006, R2009, R2010, R4003, R9002, R10001: 22.1k 0603; R_0603_1608Metric
R4001, R10002, R10003: 1R 0805; R_0805_2012Metric
R7001: 51k 0603; R_0603_1608Metric
R8004: MRF6432(2512)LR006FTS 0.006 1%; R_2512_6332Metric
S1: TS-1187A-B-A-B; TS1187ABAB
T1: H1102NLT; SOIC127P940X622-16N
TP4001: TestPoint_GND_1; TestPoint_Pad_D1.0mm
TP10001, TP11001: TestPoint_+12V; TestPoint_Pad_D1.0mm
TP10003: TestPoint_+2V5; TestPoint_Pad_D1.0mm
TP10004: TestPoint_+3V3; TestPoint_Pad_D1.0mm
TP10005: TestPoint_+1V024; TestPoint_Pad_D1.0mm
U5: LAN8742A; VQFN-24-1EP_4x4mm_P0.5mm_EP2.5x2.5mm_ThermalVias
U2001: NTJD4001NT1G; SOT-363_SC-70-6
U4001: INA181A2; SOT-23-6
U6002: ADR4525; SOIC-8_3.9x4.9mm_P1.27mm
Y1: SiT1602BI-21-33S-48.000000; Crystal_SMD_3225-4Pin_3.2x2.5mm
Y2: NX2016SA-25.000M-STD-CZS-1; Crystal_SMD_2016-4Pin_2.0x1.6mm

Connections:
+1V024: C6001.1, IC5004.6 (VREF), TP10005.1
+2V5: C28.2, C43.2, C5003.2, C5004.2, IC1.32 (VREF+), TP10003.1, U6002.6 (OUT)
+3V3: C11.2, C12.2, C26.2, C29.2, C30.2, C31.2, C32.2, C33.2, C34.2, C35.2, C36.2, C37.2, C38.2, C39.2, C40.2, C42.2, C4001.1, C5001.2, C5002.2, C6002.2, C6003.2, C7004.1, C10006.1, FB1.1, IC1.17 (VDD_1), IC1.30 (VDD_2), IC1.33 (VDDA), IC1.39 (VDD_3), IC1.52 (VDD_4), IC1.62 (VDD_5), IC1.72 (VDD_6), IC1.84 (VDD_7), IC1.95 (VDD33USB), IC1.108 (VDD_8), IC1.121 (VDD_9), IC1.131 (VDD_10), IC1.144 (VDD_11), IC5004.3 (EN), IC5004.4 (VIN), L7001.1, R1.2, R2.1, R3.2, R6.1, R27.1, R28.1, R29.1, R49.1, R56.2, R2001.1, R2004.1, R7001.1, TP10004.1, U5.9 (VDDIO), U2001.3 (D2), U2001.6 (D1), U4001.6 (V+), U6002.2 (IN), Y1.1 (OE/~ST/NC), Y1.4 (VDD)
+12V: C4004.2, C9003.1, C9004.1, IC8001.8 (+VS), L9001.1, R2007.2, R9001.1, TP10001.1
+24V: L4002.2, L8001.2, L9002.2, R2003.2, R8004.1, R8006.1, U4001.4 (-)
-12V: C4009.1, C4010.1, C4011.1, C5005.2, D2005.1 (K), IC4001.2 (GND), IC8001.5 (-VS), R4003.2, TP11001.1
/AIN0: R8.1, U4001.1
/AIN1: IC8001.7 (VOUT), R9.1
/Micro/AIN0_Filt: C44.1, IC1.13 (PF3), R8.2
/Micro/AIN1_Filt: C45.1, IC1.14 (PF4), R9.2
/Micro/AIN2_Filt: C46.1, IC1.15 (PF5), R10.2
/Micro/AIN3_Filt: C47.1, IC1.18 (PF6), R11.2
/Micro/AIN4_Filt: C48.1, IC1.19 (PF7), R22.2
/Micro/AIN5_Filt: C49.1, IC1.20 (PF8), R32.2
/Micro/AIN6_Filt: C50.1, IC1.21 (PF9), R35.2
/Micro/AIN7_Filt: C51.1, IC1.22 (PF10), R36.2
/Micro/AIN8_Filt: C52.1, IC1.26 (PC0), R37.2
/Micro/AIN9_Filt: C53.1, IC1.28 (PC2_C), R38.2
/Micro/AIN10_Filt: C54.1, IC1.29 (PC3_C), R39.2
/Micro/AIN11_Filt: C55.1, IC1.34 (PA0), R40.2
/Micro/AIN12_Filt: C56.1, IC1.37 (PA3), R41.2
/Micro/AIN15_Filt: C59.1, IC1.42 (PA6), R44.2
/Micro/AIN16_Filt: C60.1, IC1.46 (PB0), R45.2
/Micro/AIN17_Filt: C61.1, IC1.47 (PB1), R46.2
/Micro/AIN18_Filt: C62.1, IC1.49 (PF11), R51.2
/Micro/AIN19_Filt: C63.1, IC1.50 (PF12), R52.2
/Micro/DEBUG_RESET: C19.2, IC1.25 (NRST), J4.12, R2.2, S1.A1 (COM_1), U5.15 (~RST)
/Micro/DEBUG_TCK/SWCLK: IC1.109 (PA14), J4.6, R1.1
/Micro/DEBUG_TDI: IC1.110 (PA15), J4.10
/Micro/DEBUG_TDO/SWO: IC1.133 (PB3), J4.8
/Micro/DEBUG_TMS/SWDIO: IC1.105 (PA13), J4.4, R3.1
/Micro/Ethernet/RX+: R14.1, T1.6 (RD+), U5.23 (RXP)
/Micro/Ethernet/RX-: R13.1, T1.8 (RD-), U5.22 (RXN)
/Micro/Ethernet/TX+: R16.1, T1.1 (TD+), U5.21 (TXP)
/Micro/Ethernet/TX-: R15.1, T1.3 (TD-), U5.20 (TXN)
/Micro/HSECLK: IC1.23 (PH0-OSC_IN), Y1.3 (OUT)
/Micro/LED0: IC1.4 (PE5), U2001.2 (G1)
/Micro/LED1: IC1.3 (PE4), R5.2
/Micro/LED2: IC1.2 (PE3), R50.2
/Micro/LED3: IC1.1 (PE2), U2001.5 (G2)
/Micro/RMII_CRS_DV: IC1.43 (PA7), R47.1
/Micro/RMII_MDC: IC1.27 (PC1), U5.13 (MDC)
/Micro/RMII_MDIO: IC1.36 (PA2), R56.1, U5.12 (MDIO)
/Micro/RMII_REF_CLK: IC1.35 (PA1), R48.2
/Micro/RMII_RXD0: IC1.44 (PC4), R26.2
/Micro/RMII_RXD1: IC1.45 (PC5), R23.2
/Micro/RMII_TXD0: IC1.128 (PG13), U5.17 (TXD0)
/Micro/RMII_TXD1: IC1.74 (PB13), U5.18 (TXD1)
/Micro/RMII_TX_EN: IC1.126 (PG11), U5.16 (TXEN)
/Micro/UART_RX: IC1.78 (PD9), J4.13
/Micro/UART_TX: IC1.77 (PD8), J4.14
GND: C9.1, C10.2, C11.1, C12.1, C13.1, C14.1, C15.1, C16.2, C17.1, C18.1, C19.1, C22.1, C23.1, C24.1, C25.1, C26.1, C27.1, C28.1, C29.1, C30.1, C31.1, C32.1, C33.1, C34.1, C35.1, C36.1, C37.1, C38.1, C39.1, C40.1, C42.1, C43.1, C44.2, C45.2, C46.2, C47.2, C48.2, C49.2, C50.2, C51.2, C52.2, C53.2, C54.2, C55.2, C56.2, C59.2, C60.2, C61.2, C62.2, C63.2, C4001.2, C4002.2, C4004.1, C4007.2, C4009.2, C4010.2, C5001.1, C5002.1, C5003.1, C5004.1, C5005.1, C6001.2, C6002.1, C6003.1, C7002.2, C7004.2, C9001.2, C9003.2, C9004.2, C10002.2, C10005.2, C10006.2, D6.1 (K), D37.1 (K), D38.1 (K), D39.1 (K), D2001.1 (K), D2003.1 (K), D2004.1 (K), IC1.16 (VSS_1), IC1.31 (VSSA), IC1.38 (VSS_2), IC1.51 (VSS_3), IC1.61 (VSS_4), IC1.83 (VSS_5), IC1.94 (VSS_6), IC1.107 (VSS_7), IC1.120 (VSS_8), IC1.130 (VSS_9), IC5004.1 (GND_1), IC5004.2 (GND_2), IC8001.1 (-IN1), IC8001.6 (REF), IC10001.2 (GND), IC10002.2 (GND), J4.5, J4.7, J3001.9 (MH1), J3001.10 (MH2), J8001.2, L4001.2, R4.2, R21.2, R30.1, R31.2, R33.2, R34.1, R57.1, R58.1, R2008.2, R4001.2, R4002.1, R8005.1, R9002.2, R10001.2, R10002.2, R10003.2, S1.C1 (NO_1), TP4001.1, U5.25 (VSS), U4001.2 (GND), U4001.5 (REF), U6002.4 (GND), Y1.2 (GND), Y2.2 (GND_1), Y2.4 (GND_2)
unnamed: C16.1, R17.2, R18.1, R19.1, R20.2, R21.1
unnamed: C4006.2, R4001.1
unnamed: C7001.2, R10003.1
unnamed: C10001.2, R10002.1
unnamed: D2.2 (A), U5.3 (LED1/REGOFF)
unnamed: D2.1 (K), R31.1
unnamed: D6.2 (A), R5.1
unnamed: D36.2 (A), R33.1, U5.2 (LED2/~INTSEL)
unnamed: D36.1 (K), R34.2
unnamed: D37.2 (A), R50.1
unnamed: D38.2 (A), R2014.2
unnamed: D39.2 (A), R2012.2
unnamed: D2001.2 (A), R2002.2
unnamed: D2003.2 (A), R2005.1
unnamed: D2004.2 (A), R2003.1
unnamed: D2005.2 (A), R2010.1
unnamed: IC1.138 (BOOT0), R4.1
unnamed: IC1.143 (PDR_ON), R6.2
unnamed: C9.2, C18.2, IC1.71 (VCAP_1)
unnamed: C10.1, C17.2, IC1.106 (VCAP_2)
unnamed: C4008.1, IC4001.1 (CB)
unnamed: C4002.1, C4006.1, C4007.1, C4011.2, IC4001.4 (EN), IC4001.5 (VIN), L4002.1
unnamed: IC4001.3 (FB), R4002.2, R4003.1
unnamed: C4008.2, IC4001.6 (SW), L4001.1
unnamed: IC8001.4 (+IN), R8005.2, R8007.1
unnamed: C7003.2, IC10001.1 (CB)
unnamed: C7001.1, C7002.1, C10005.1, IC10001.4 (EN), IC10001.5 (VIN), L8001.1
unnamed: IC10001.3 (FB), R7001.2, R10001.1
unnamed: C7003.1, IC10001.6 (SW), L7001.2
unnamed: C9002.2, IC10002.1 (CB)
unnamed: C9001.1, C10001.1, C10002.1, IC10002.4 (EN), IC10002.5 (VIN), L9002.1
unnamed: IC10002.3 (FB), R9001.2, R9002.1
unnamed: C9002.1, IC10002.6 (SW), L9001.2
unnamed: J4.3, R2001.2
unnamed: J4.11, R58.2
unnamed: J3001.4, J3001.5, R19.2
unnamed: J3001.7, J3001.8, R20.1
unnamed: R54.1, R57.2
unnamed: R2002.1, R2004.2
unnamed: R2005.2, R2006.2
unnamed: R2006.1, R2007.1
unnamed: R2008.1, R2009.1
unnamed: R2009.2, R2010.2
unnamed: R2011.2, R2012.1
unnamed: R2013.2, R2014.1
unnamed: R8006.2, R8007.2
unnamed: C13.2, C14.2, C15.2, C22.2, C23.2, C24.2, FB1.2, R13.2, R14.2, R15.2, R16.2, T1.2 (CT_1), T1.7 (CT_2), U5.1 (VDD2A), U5.19 (VDD1A)
unnamed: R17.1, T1.10 (NC_3)
unnamed: R18.2, T1.15 (NC_6)
unnamed: D5.3 (TVS1), D5.6 (TVS2), J3001.3, T1.11 (RX+)
unnamed: D5.4 (TVS2), D5.5 (TVS1), J3001.6, T1.9 (RX-)
unnamed: D5.1 (TVS1), D5.8 (TVS2), J3001.1, T1.16 (TX+)
unnamed: D5.2 (TVS2), D5.7 (TVS1), J3001.2, T1.14 (TX-)
unnamed: R28.2, R47.2, U5.11 (CRS_DV/MODE2)
unnamed: R54.2, U5.24 (RBIAS)
unnamed: R26.1, R49.2, U5.8 (RXD0/MODE0)
unnamed: R23.1, R27.2, U5.7 (RXD1/MODE1)
unnamed: R30.2, U5.10 (RXER/PHYAD0)
unnamed: C25.2, C27.2, U5.6 (VDDCR)
unnamed: U5.5 (XTAL1/CLKIN), Y2.3 (CRYSTAL_2)
unnamed: U5.4 (XTAL2), Y2.1 (CRYSTAL_1)
unnamed: R29.2, R48.1, U5.14 (~INT/REFCLKO)
unnamed: R2011.1, U2001.1 (S1)
unnamed: R2013.1, U2001.4 (S2)
unnamed: J8001.1, R8004.2, U4001.3 (+)

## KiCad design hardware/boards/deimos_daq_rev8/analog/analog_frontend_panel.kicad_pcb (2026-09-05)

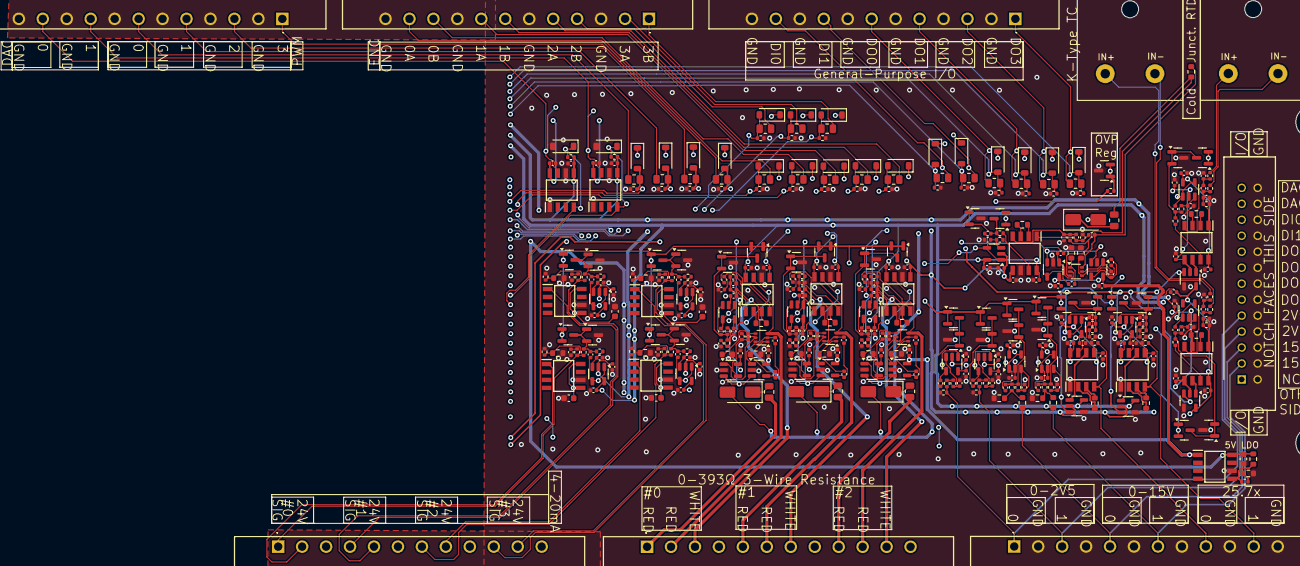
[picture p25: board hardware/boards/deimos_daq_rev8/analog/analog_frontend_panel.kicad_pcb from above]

Board: 4 copper layers, 379 parts (0 on the bottom side), 202 nets.

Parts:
C1, C3, C7, C9, C49, C51, C60, C62, C71, C73, C82, C84: 2.2uF; C_0402_1005Metric
C2, C8, C50, C61, C72, C83: 1uF; C_0402_1005Metric
C4, C10, C52, C55, C58, C63, C66, C69, C74, C77, C80, C85, C88, C91, C5003, C5004, C6001, C7001, C8003, C8004, C9003, C9004, C14001, C14002, C15003, C15004, C16003, C16004, C17003, C17004, C18003, C18004, C20003, C20004, C21003, C21004, C24003, C24004, C25003, C25004, C28001, C28002, C28005, C28006, C30003, C30004, C31001, C31002, C31003, C32006, C33007, C34002, C37001, C39003, C42002, C42003, C44004, C45002, C46001, C47001: 0.1uF; C_0402_1005Metric
C25, C28, C31, C34, C44005, C44006, C45003, C45004, C46002, C46003, C47002, C47003: 10nF; C_0402_1005Metric
C1001, C10001, C11001, C12001, C13001: 0.1uF 50V 0603; C_0603_1608Metric
C5001, C5002, C8001, C8002, C9001, C9002, C15001, C15002, C16001, C16002, C17001, C17002, C18001, C18002, C20001, C20002, C21001, C21002, C24001, C24002, C25001, C25002, C28003, C28004, C30001, C30002, C32002, C32003, C33002, C33003, C44001, C44002: 10nF C0G 5%; C_0402_1005Metric
D7, D8, D9, D10: D_Schottky; D_SMA
D19001, D26001, D27001, D29002, D34001, D36002, D37001, D38002, D39003, D40003, D41001, D42002, D43001, D45002, D46001, D47001, D49001, D50001, D51002, D52002: B5819W SL; D_SOD-123
H1001, H1002: MountingHole_for_10-32; MountingHole_5mm
IC1, IC2, IC12, IC15, IC18, IC21, IC14001, IC31001, IC34002, IC37001: INA826AIDR; SOIC127P600X175-8N
IC13, IC14, IC16, IC17, IC19, IC20, IC22, IC23: TLV333IDBVR; SOT-23-5
IC1002, IC32001, IC33001, IC34001, IC35001: BD42540FJ-CE2; SOIC127P600X175-8N
J12, J13: AM-K-PCB
J1001, J1002, J1003, J1004, J1005, J1007: WJ15EDGRM-3.81-12P
J1006: XG4C-2631; SHDR26W70P254_2X13_4030X820X900P
Q5001, Q5002, Q8001, Q8002, Q9001, Q9002, Q15001, Q15002, Q16001, Q16002, Q17001, Q17002, Q18001, Q18002, Q20001, Q20002, Q21001, Q21002, Q24001, Q24002, Q25001, Q25002, Q28001, Q28002, Q28003, Q28004, Q30001, Q30002, Q31001, Q31002, Q42001, Q42002: MMBFJ113; SOT-23
R1: PTS060301B100RP100; R_0603_1608Metric
R2, R3, R7, R8: 10; R_0402_1005Metric
R4, R9, R10001, R11001, R12001, R13001, R14002, R19001, R22001, R26001, R27001, R27003, R29002, R31002, R33003, R36002, R38002, R39002, R39004, R40002, R42002, R45006, R46003, R47003, R49001, R50001, R51002, R52002: 1M; R_0402_1005Metric
R6, R11, R40, R49, R58, R67, R14001, R23002, R31001, R45003: RNCF0603TKY2K00 2k 0.01% 5ppm/C; R_0603_1608Metric
R22, R24, R26, R28: 200R; R_0402_1005Metric
R23, R25, R27, R29: RNCF0603TKY75R0 75R 0.01% 5ppm/C; R_0603_1608Metric
R41, R50, R59, R68: 300; R_0805_2012Metric
R42, R43, R51, R52, R60, R61, R69, R70: 10; C_0402_1005Metric
R44, R47, R53, R56, R62, R65, R71, R74, R23001, R45004: RNCF0603TKW10K0 10k 0.01% 5ppm/C; R_0603_1608Metric
R1001, R5001, R5002, R8001, R8002, R9001, R9002, R28001, R28002: 10k 1%; R_0402_1005Metric
R1002: 51k 0603; R_0603_1608Metric
R1003: 243k 0603; R_0603_1608Metric
R1004, R15001, R15002, R16001, R16002, R17001, R17002, R18001, R18002, R21001, R21002, R24001, R24002, R25001, R25002, R30001, R30002, R32001, R32002, R33001, R33002, R33005, R40003, R44001, R44002: 3.3k 1%; R_0402_1005Metric
R19002, R26002, R27002, R33004, R46004, R47004, R49002, R50002: 49.9; R_0805_2012Metric
R20001, R20002: 100k 1%; R_0402_1005Metric
R29001, R36001, R38001, R39001, R39003, R40001, R42001, R45005, R51001, R52001: 22k; R_0805_2012Metric
R44003, R44004, R45001, R45002, R46001, R46002, R47001, R47002: 10k 1%; C_0402_1005Metric
U1, U2, U3, U4: NTJD4001NT1G; SOT-363_SC-70-6
U1001: ATL431BQDBZR; SOT-23
U5001, U6001, U7001, U8001, U9001, U14001, U15001, U16001, U17001, U18001, U20002, U21001, U24001, U25001, U28001, U28002, U30001, U31001, U35001, U42002: OPA196xDBV; SOT-23-5

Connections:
2V5_OVP: Q5001.1 (D), Q5001.2 (S), Q8001.1 (D), Q8001.2 (S), Q9001.1 (D), Q9001.2 (S), Q15001.1 (D), Q15001.2 (S), Q16001.1 (D), Q16001.2 (S), Q17001.1 (D), Q17001.2 (S), Q18001.1 (D), Q18001.2 (S), Q20001.1 (D), Q20001.2 (S), Q21001.1 (D), Q21001.2 (S), Q24001.1 (D), Q24001.2 (S), Q25001.1 (D), Q25001.2 (S), Q28001.1 (D), Q28001.2 (S), Q28003.1 (D), Q28003.2 (S), Q30001.1 (D), Q30001.2 (S), Q31001.1 (D), Q31001.2 (S), Q42001.1 (D), Q42001.2 (S), R1004.1, U1001.1 (K), U1001.2 (REF)
+1V024: U6001.3 (+), U7001.3 (+), U14001.3 (+), U35001.3 (+)
+2V5: IC13.3 (+IN), IC14.3 (+IN), IC16.3 (+IN), IC17.3 (+IN), IC19.3 (+IN), IC20.3 (+IN), IC22.3 (+IN), IC23.3 (+IN)
+3V3: D7.2 (A), D8.2 (A), D9.2 (A), D10.2 (A), D19001.1 (K), D26001.1 (K), D27001.1 (K), D29002.1 (K), D36002.1 (K), D37001.1 (K), D38002.1 (K), D39003.1 (K), D40003.1 (K), D42002.1 (K), D43001.1 (K), D45002.1 (K), D46001.1 (K), D47001.1 (K), D49001.1 (K), D50001.1 (K), D51002.1 (K), D52002.1 (K), R1004.2
+5V: C55.1, C58.1, C66.1, C69.1, C77.1, C80.1, C88.1, C91.1, IC13.5 (V+), IC14.5 (V+), IC16.5 (V+), IC17.5 (V+), IC19.5 (V+), IC20.5 (V+), IC22.5 (V+), IC23.5 (V+), IC1002.1 (VO)
+12V: C4.1, C10.1, C52.1, C63.1, C74.1, C85.1, C5003.2, C8003.2, C9003.2, C14001.2, C15003.2, C16003.2, C17003.2, C18003.2, C20003.2, C21003.2, C24003.2, C25003.2, C28001.2, C28005.2, C30003.2, C31001.2, C31002.2, C34002.2, C37001.2, C42002.2, IC1.8 (+VS), IC2.8 (+VS), IC12.8 (+VS), IC15.8 (+VS), IC18.8 (+VS), IC21.8 (+VS), IC14001.8 (+VS), IC31001.8 (+VS), IC34002.8 (+VS), IC37001.8 (+VS), U5001.5 (V+), U6001.5 (V+), U7001.5 (V+), U8001.5 (V+), U9001.5 (V+), U14001.5 (V+), U15001.5 (V+), U16001.5 (V+), U17001.5 (V+), U18001.5 (V+), U20002.5 (V+), U21001.5 (V+), U24001.5 (V+), U25001.5 (V+), U28001.5 (V+), U28002.5 (V+), U30001.5 (V+), U31001.5 (V+), U35001.5 (V+), U42002.5 (V+)
+24V: C1001.2, C10001.2, C11001.2, C12001.2, C13001.2, IC1002.8 (VCC), IC32001.5 (ADJ_/_EN), IC32001.8 (VCC), IC33001.5 (ADJ_/_EN), IC33001.8 (VCC), IC34001.5 (ADJ_/_EN), IC34001.8 (VCC), IC35001.5 (ADJ_/_EN), IC35001.8 (VCC), R1003.2
-12V: C5004.2, C6001.2, C7001.2, C8004.2, C9004.2, C14002.2, C15004.2, C16004.2, C17004.2, C18004.2, C20004.2, C21004.2, C24004.2, C25004.2, C28002.2, C28006.2, C30004.2, C31003.2, C32006.2, C33007.2, C39003.2, C42003.2, C44004.1, C45002.1, C46001.1, C47001.1, IC1.5 (-VS), IC2.5 (-VS), IC12.5 (-VS), IC15.5 (-VS), IC18.5 (-VS), IC21.5 (-VS), IC14001.5 (-VS), IC31001.5 (-VS), IC34002.5 (-VS), IC37001.5 (-VS), R33005.1, R40003.1, U5001.2 (V-), U6001.2 (V-), U7001.2 (V-), U8001.2 (V-), U9001.2 (V-), U14001.2 (V-), U15001.2 (V-), U16001.2 (V-), U17001.2 (V-), U18001.2 (V-), U20002.2 (V-), U21001.2 (V-), U24001.2 (V-), U25001.2 (V-), U28001.2 (V-), U28002.2 (V-), U30001.2 (V-), U31001.2 (V-), U35001.2 (V-), U42002.2 (V-)
/2p5V_0: J1003.1, J1006.9, R21001.1, R27003.1
/2p5V_1: J1003.3, J1006.7, R22001.1, R25001.1
/4-20mA Frontend1/+24_EXC: IC33001.1 (VO), J1004.5
/4-20mA Frontend1/SIGNAL: J1004.4, R24.2, R25.2, R11001.1, R30001.1
/4-20mA Frontend2/+24_EXC: IC34001.1 (VO), J1004.8
/4-20mA Frontend2/SIGNAL: J1004.7, R26.2, R27.2, R12001.1, R32001.1
/4-20mA Frontend3/+24_EXC: IC35001.1 (VO), J1004.11
/4-20mA Frontend3/SIGNAL: J1004.10, R28.2, R29.2, R13001.1, R33001.1
/4-20mA Frontend/+24_EXC: IC32001.1 (VO), J1004.2
/4-20mA Frontend/SIGNAL: J1004.1, R22.2, R23.2, R10001.1, R16001.1
/15V_0: J1003.5, J1006.5, R45004.2
/15V_1: J1003.7, J1006.3, R23001.2
/25p7x_0: IC31001.4 (+IN), J1003.9, R31002.1
/25p7x_1: IC14001.4 (+IN), J1003.11, R14002.1
/AIN2: C20002.2, U20002.1, U20002.4 (-)
/AIN3: C16002.2, U16001.1, U16001.4 (-)
/AIN4: C30002.2, U28001.1, U28001.4 (-)
/AIN5: C32003.2, U30001.1, U30001.4 (-)
/AIN6: C33003.2, U31001.1, U31001.4 (-)
/AIN7: C15002.2, U15001.1, U15001.4 (-)
/AIN8: C17002.2, U17001.1, U17001.4 (-)
/AIN9: C18002.2, U18001.1, U18001.4 (-)
/AIN10: C5002.2, U5001.1, U5001.4 (-)
/AIN11: C8002.2, U8001.1, U8001.4 (-)
/AIN12: C21002.2, U21001.1, U21001.4 (-)
/AIN13_DAC0: D41001.1 (K), IC37001.4 (+IN), R40003.2
/AIN14_DAC1: D34001.1 (K), IC34002.4 (+IN), R33005.2
/AIN15: C25002.2, U25001.1, U25001.4 (-)
/AIN16: C44002.2, U42002.1, U42002.4 (-)
/AIN17: C24002.2, U24001.1, U24001.4 (-)
/AIN18: C9002.2, U9001.1, U9001.4 (-)
/AIN19: C28004.2, U28002.1, U28002.4 (-)
/DAC0: IC37001.7 (VOUT), J1002.11, J1006.25
/DAC1: IC34002.7 (VOUT), J1002.9, J1006.23
/DI0: D29002.2 (A), R29001.2, R29002.1
/DI0_CONN: J1006.21, J1007.11, R29001.1
/DI1: D45002.2 (A), R45005.2, R45006.1
/DI1_CONN: J1006.19, J1007.9, R45005.1
/DO0: D46001.2 (A), R46003.1, R46004.1
/DO0_CONN: J1006.17, J1007.7, R46004.2
/DO1: D47001.2 (A), R47003.1, R47004.1
/DO1_CONN: J1006.15, J1007.5, R47004.2
/DO2: D49001.2 (A), R49001.1, R49002.1
/DO2_CONN: J1006.13, J1007.3, R49002.2
/DO3: D50001.2 (A), R50001.1, R50002.1
/DO3_CONN: J1006.11, J1007.1, R50002.2
/ENCODER0_A: D38002.2 (A), R38001.2, R38002.1
/ENCODER0_B: D43001.2 (A), R39001.2, R39002.1
/ENCODER1_A: D42002.2 (A), R42001.2, R42002.1
/ENCODER1_B: D40003.2 (A), R40001.2, R40002.1
/ENCODER2_A: D39003.2 (A), R39003.2, R39004.1
/ENCODER2_B: D36002.2 (A), R36001.2, R36002.1
/ENCODER3_A: D51002.2 (A), R51001.2, R51002.1
/ENCODER3_B: D52002.2 (A), R52001.2, R52002.1
/K-Type TC Amp1/Signal+: C7.1, C8.1, IC2.4 (+IN), R7.2
/K-Type TC Amp1/Signal-: C8.2, C9.1, IC2.1 (-IN1), R8.1, R9.1
/K-Type TC Amp1/sallen_key_1kHz/VIN: IC2.7 (VOUT), R8001.1
/K-Type TC Amp/Signal+: C1.1, C2.1, IC1.4 (+IN), R2.2
/K-Type TC Amp/Signal-: C2.2, C3.1, IC1.1 (-IN1), R3.1, R4.1
/K-Type TC Amp/sallen_key_1kHz/VIN: IC1.7 (VOUT), R5001.1
/PWM0: D37001.2 (A), R33003.1, R33004.1
/PWM1: D19001.2 (A), R19001.1, R19002.1
/PWM2: D26001.2 (A), R26001.1, R26002.1
/PWM3: D27001.2 (A), R27001.1, R27002.1
/RTD Amp1/R+: J1005.5, R59.2
/RTD Amp1/R-: J1005.6, R60.2, U3.3 (D2)
/RTD Amp1/W-: J1005.7, R61.2, U3.6 (D1)
/RTD Amp1/rtd_amp_inner/Signal+: C71.2, C72.1, IC18.4 (+IN), R60.1
/RTD Amp1/rtd_amp_inner/Signal-: C72.2, C73.1, IC18.1 (-IN1), R61.1
/RTD Amp1/rtd_amp_inner/Vout: IC18.7 (VOUT), R17001.1
/RTD Amp2/R+: J1005.9, R68.2
/RTD Amp2/R-: J1005.10, R69.2, U4.3 (D2)
/RTD Amp2/W-: J1005.11, R70.2, U4.6 (D1)
/RTD Amp2/rtd_amp_inner/Signal+: C82.2, C83.1, IC21.4 (+IN), R69.1
/RTD Amp2/rtd_amp_inner/Signal-: C83.2, C84.1, IC21.1 (-IN1), R70.1
/RTD Amp2/rtd_amp_inner/Vout: IC21.7 (VOUT), R18001.1
/RTD Amp/R+: J1005.1, R41.2
/RTD Amp/R-: J1005.2, R42.2, U1.3 (D2)
/RTD Amp/W-: J1005.3, R43.2, U1.6 (D1)
/RTD Amp/rtd_amp_inner/Signal+: C49.2, C50.1, IC12.4 (+IN), R42.1
/RTD Amp/rtd_amp_inner/Signal-: C50.2, C51.1, IC12.1 (-IN1), R43.1
/RTD Amp/rtd_amp_inner/Vout: IC12.7 (VOUT), R15001.1
/ain_0-15V_1/sallen_key_3kHz8/VIN: R23001.1, R23002.1, R24001.1
/ain_0-15V_/sallen_key_3kHz8/VIN: R44001.1, R45003.1, R45004.1
/ain_g25p7_1/sallen_key_1kHz2/VIN: IC14001.7 (VOUT), R28001.1
/ain_g25p7_/sallen_key_1kHz2/VIN: IC31001.7 (VOUT), R9001.1
/pwm_in_buf1/VIN: J1001.11, R38001.1
/pwm_in_buf2/VIN: J1001.5, R39003.1
/pwm_in_buf3/VIN: J1001.7, R40001.1
/pwm_in_buf4/VIN: J1001.8, R42001.1
/pwm_in_buf5/VIN: J1001.4, R36001.1
/pwm_in_buf8/VIN: J1001.2, R51001.1
/pwm_in_buf9/VIN: J1001.1, R52001.1
/pwm_in_buf/VIN: J1001.10, R39001.1
/pwm_out_buf1/VOUT: J1002.5, R19002.2
/pwm_out_buf2/VOUT: J1002.3, R26002.2
/pwm_out_buf3/VOUT: J1002.1, R27002.2
/pwm_out_buf/VOUT: J1002.7, R33004.2
/rtd_amp_inner1/250uA_SINK_1: R1.1, R52.2, U2.6 (D1)
/rtd_amp_inner1/250uA_SINK_2: R1.2, R50.2, R51.2, U2.3 (D2)
/rtd_amp_inner1/Signal+: C60.2, C61.1, IC15.4 (+IN), R51.1
/rtd_amp_inner1/Signal-: C61.2, C62.1, IC15.1 (-IN1), R52.1
/rtd_amp_inner1/Vout: IC15.7 (VOUT), R20002.2
GND: C1.2, C3.2, C4.2, C7.2, C9.2, C10.2, C25.2, C28.2, C31.2, C34.2, C49.1, C51.2, C52.2, C55.2, C58.2, C60.1, C62.2, C63.2, C66.2, C69.2, C71.1, C73.2, C74.2, C77.2, C80.2, C82.1, C84.2, C85.2, C88.2, C91.2, C1001.1, C5001.1, C5003.1, C5004.1, C6001.1, C7001.1, C8001.1, C8003.1, C8004.1, C9001.1, C9003.1, C9004.1, C10001.1, C11001.1, C12001.1, C13001.1, C14001.1, C14002.1, C15001.1, C15003.1, C15004.1, C16001.1, C16003.1, C16004.1, C17001.1, C17003.1, C17004.1, C18001.1, C18003.1, C18004.1, C20001.1, C20003.1, C20004.1, C21001.1, C21003.1, C21004.1, C24001.1, C24003.1, C24004.1, C25001.1, C25003.1, C25004.1, C28001.1, C28002.1, C28003.1, C28005.1, C28006.1, C30001.1, C30003.1, C30004.1, C31001.1, C31002.1, C31003.1, C32002.1, C32006.1, C33002.1, C33007.1, C34002.1, C37001.1, C39003.1, C42002.1, C42003.1, C44001.1, C44004.2, C45002.2, C46001.2, C47001.2, D34001.2 (A), D41001.2 (A), IC12.6 (REF), IC13.2 (V-), IC14.2 (V-), IC15.6 (REF), IC16.2 (V-), IC17.2 (V-), IC18.6 (REF), IC19.2 (V-), IC20.2 (V-), IC21.6 (REF), IC22.2 (V-), IC23.2 (V-), IC1002.6 (GND), IC14001.1 (-IN1), IC31001.1 (-IN1), IC32001.6 (GND), IC33001.6 (GND), IC34001.6 (GND), IC34002.1 (-IN1), IC34002.6 (REF), IC35001.6 (GND), IC37001.1 (-IN1), IC37001.6 (REF), J1001.3, J1001.6, J1001.9, J1001.12, J1002.2, J1002.4, J1002.6, J1002.8, J1002.10, J1002.12, J1003.2, J1003.4, J1003.6, J1003.8, J1003.10, J1003.12, J1006.2, J1006.4, J1006.6, J1006.8, J1006.10, J1006.12, J1006.14, J1006.16, J1006.18, J1006.20, J1006.22, J1006.24, J1006.26, J1007.2, J1007.4, J1007.6, J1007.8, J1007.10, J1007.12, Q5002.3 (G), Q8002.3 (G), Q9002.3 (G), Q15002.3 (G), Q16002.3 (G), Q17002.3 (G), Q18002.3 (G), Q20002.3 (G), Q21002.3 (G), Q24002.3 (G), Q25002.3 (G), Q28002.3 (G), Q28004.3 (G), Q30002.3 (G), Q31002.3 (G), Q42002.3 (G), R4.2, R9.2, R23.1, R25.1, R27.1, R29.1, R44.2, R47.2, R53.2, R56.2, R62.2, R65.2, R71.2, R74.2, R1002.1, R10001.2, R11001.2, R12001.2, R13001.2, R14002.2, R19001.2, R22001.2, R23002.2, R26001.2, R27001.2, R27003.2, R29002.2, R31002.2, R33003.2, R36002.2, R38002.2, R39002.2, R39004.2, R40002.2, R42002.2, R45003.2, R45006.2, R46003.2, R47003.2, R49001.2, R50001.2, R51002.2, R52002.2, U1001.3 (A), U6001.4 (-), U7001.4 (-), U14001.4 (-), U35001.4 (-)
unnamed: C25.1, R22.1
unnamed: C28.1, R24.1
unnamed: C31.1, R26.1
unnamed: C34.1, R28.1
unnamed: D7.1 (K), R41.1
unnamed: D8.1 (K), R50.1
unnamed: D9.1 (K), R59.1
unnamed: D10.1 (K), R68.1
unnamed: IC1.6 (REF), U6001.1
unnamed: IC1.2 (RG_1), R6.1
unnamed: IC1.3 (RG_2), R6.2
unnamed: IC2.6 (REF), U7001.1
unnamed: IC2.2 (RG_1), R11.1
unnamed: IC2.3 (RG_2), R11.2
unnamed: IC12.2 (RG_1), R40.1
unnamed: IC12.3 (RG_2), R40.2
unnamed: C45003.1, IC13.4 (-IN), R45001.2
unnamed: C45003.2, IC13.1 (OUT), U1.2 (G1)
unnamed: C45004.1, IC14.4 (-IN), R45002.1
unnamed: C45004.2, IC14.1 (OUT), U1.5 (G2)
unnamed: IC15.2 (RG_1), R49.1
unnamed: IC15.3 (RG_2), R49.2
unnamed: C44005.1, IC16.4 (-IN), R44003.2
unnamed: C44005.2, IC16.1 (OUT), U2.2 (G1)
unnamed: C44006.1, IC17.4 (-IN), R44004.1
unnamed: C44006.2, IC17.1 (OUT), U2.5 (G2)
unnamed: IC18.2 (RG_1), R58.1
unnamed: IC18.3 (RG_2), R58.2
unnamed: C46002.1, IC19.4 (-IN), R46001.2
unnamed: C46002.2, IC19.1 (OUT), U3.2 (G1)
unnamed: C46003.1, IC20.4 (-IN), R46002.1
unnamed: C46003.2, IC20.1 (OUT), U3.5 (G2)
unnamed: IC21.2 (RG_1), R67.1
unnamed: IC21.3 (RG_2), R67.2
unnamed: C47002.1, IC22.4 (-IN), R47001.2
unnamed: C47002.2, IC22.1 (OUT), U4.2 (G1)
unnamed: C47003.1, IC23.4 (-IN), R47002.1
unnamed: C47003.2, IC23.1 (OUT), U4.5 (G2)
unnamed: IC1002.5 (ADJ_/_EN), R1001.1, R1003.1
unnamed: IC14001.6 (REF), U14001.1
unnamed: IC14001.2 (RG_1), R14001.1
unnamed: IC14001.3 (RG_2), R14001.2
unnamed: IC31001.6 (REF), U35001.1
unnamed: IC31001.2 (RG_1), R31001.1
unnamed: IC31001.3 (RG_2), R31001.2
unnamed: J12.1, R3.2
unnamed: J12.2, R2.1
unnamed: J13.1, R8.2
unnamed: J13.2, R7.1
unnamed: C5002.1, Q5001.3 (G), Q5002.1 (D), Q5002.2 (S), R5001.2, R5002.1
unnamed: C8002.1, Q8001.3 (G), Q8002.1 (D), Q8002.2 (S), R8001.2, R8002.1
unnamed: C9002.1, Q9001.3 (G), Q9002.1 (D), Q9002.2 (S), R9001.2, R9002.1
unnamed: C15002.1, Q15001.3 (G), Q15002.1 (D), Q15002.2 (S), R15001.2, R15002.1
unnamed: C16002.1, Q16001.3 (G), Q16002.1 (D), Q16002.2 (S), R16001.2, R16002.1
unnamed: C17002.1, Q17001.3 (G), Q17002.1 (D), Q17002.2 (S), R17001.2, R17002.1
unnamed: C18002.1, Q18001.3 (G), Q18002.1 (D), Q18002.2 (S), R18001.2, R18002.1
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

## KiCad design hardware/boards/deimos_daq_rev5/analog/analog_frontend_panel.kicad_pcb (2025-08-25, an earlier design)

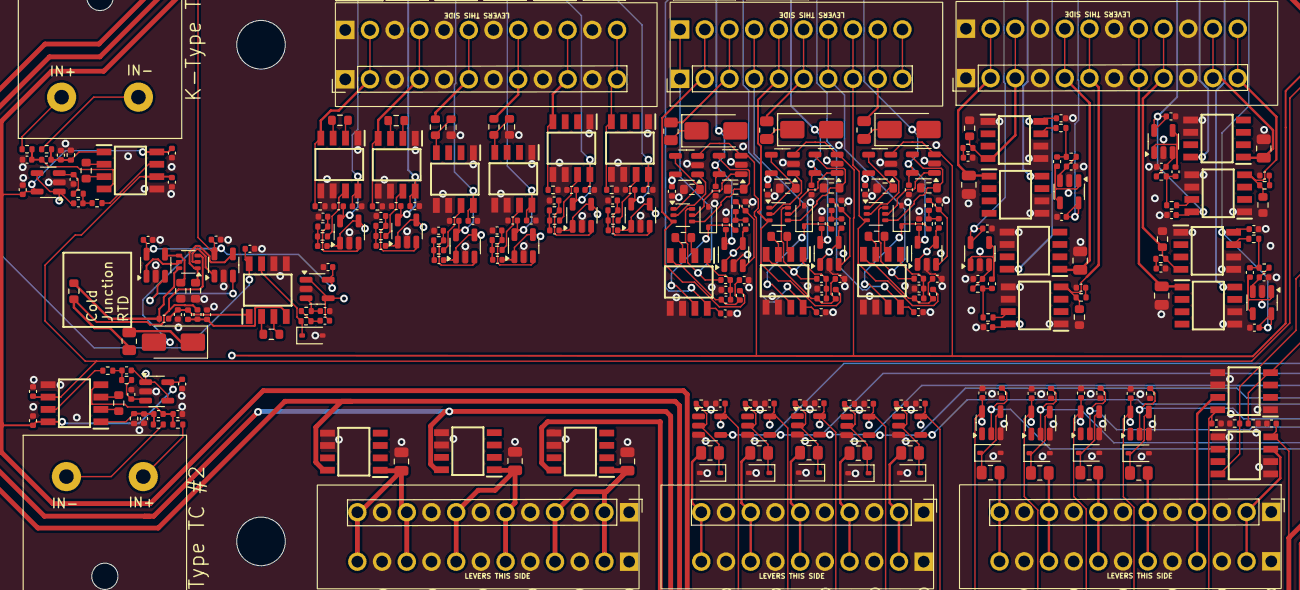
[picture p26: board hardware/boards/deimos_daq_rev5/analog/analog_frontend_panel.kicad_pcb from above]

Board: 4 copper layers, 308 parts (0 on the bottom side), 182 nets.

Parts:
C1, C3, C7, C9: 2.2uF; C_0402_1005Metric
C2, C8: 1uF; C_0402_1005Metric
C4, C6, C10, C12, C26, C29, C32, C35, C52, C55, C58, C63, C66, C69, C74, C77, C80, C85, C88, C91, C5003, C8003, C9003, C14003, C15003, C16003, C17003, C18003, C19001, C20003, C21003, C22001, C23001, C24003, C25003, C26001, C27001, C27004, C30003, C31001, C32004, C32005, C33004, C33005, C34002, C37001, C38001, C39001, C39002, C40001, C42001, C44003, C45001: 0.1uF; C_0402_1005Metric
C25, C28, C31, C34, C50, C61, C72, C83: 10nF; C_0402_1005Metric
C49, C51, C60, C62, C71, C73, C82, C84: 1nF; C_0402_1005Metric
C1001, C1002, C1003, C32001, C33001, C34001, C35001: 10uF 50V 0805; C_0805_2012Metric
C5001, C5002, C8001, C8002, C9001, C9002, C14001, C14002, C15001, C15002, C16001, C16002, C17001, C17002, C18001, C18002, C20001, C20002, C21001, C21002, C24001, C24002, C25001, C25002, C30001, C30002, C32002, C32003, C33002, C33003, C44001, C44002: 10nF C0G 5%; C_0402_1005Metric
D7, D8, D9, D10: D_Schottky; D_SMA
D19001, D26001, D27001, D33001, D38001, D39001, D39002, D40001, D42001: BZT52C5V6S; D_SOD-323
D44001, D45001, D46001, D47001: BZT52C3V3; D_SOD-323
H1001, H1002, H1003, H1004: MountingHole_for_10-32; MountingHole_5mm
IC1, IC2, IC5, IC6, IC7, IC8, IC12, IC15, IC18, IC21, IC22001, IC23001, IC27001, IC31001, IC32002, IC34002, IC37001, IC45001: INA826AIDR; SOIC127P600X175-8N
IC13, IC14, IC16, IC17, IC19, IC20, IC22, IC23: TLV333IDBVR; SOT-23-5
IC1001, IC1002, IC1003, IC32001, IC33001, IC34001, IC35001: BD42540FJ-CE2; SOIC127P600X175-8N
J12, J13: AM-K-PCB
J1001, J1004, J1005, J1007: Screw_Terminal_01x12; KF141V-2.54-12P
J1003, J1006: Screw_Terminal_01x10; KF141V-2.54-10P
R1: PTS060301B100RP100; R_0603_1608Metric
R2, R3, R7, R8: 10; R_0402_1005Metric
R4, R9, R19001, R22001, R26001, R27001, R27003, R31002, R32004, R33003, R34001, R37001, R38002, R39002, R39004, R40002, R42002: 1M; R_0402_1005Metric
R6, R11, R40, R49, R58, R67, R23002, R31001, R45003: RNCF0603TKY2K00 2k 0.01% 5ppm/C; R_0603_1608Metric
R22, R24, R26, R28: 200R; R_0402_1005Metric
R23, R25, R27, R29, R32003: RNCF0603TKY75R0 75R 0.01% 5ppm/C; R_0603_1608Metric
R41, R50, R59, R68: 300; R_0805_2012Metric
R42, R43, R51, R52, R60, R61, R69, R70: 10k 1%; C_0402_1005Metric
R44, R47, R53, R56, R62, R65, R71, R74, R23001, R45004: RNCF0603TKW10K0 10k 0.01% 5ppm/C; R_0603_1608Metric
R5001, R5002, R8001, R8002, R9001, R9002: 10k 1%; R_0402_1005Metric
R14001, R14002, R20001, R20002: 100k 1%; R_0402_1005Metric
R15001, R15002, R16001, R16002, R17001, R17002, R18001, R18002, R21001, R21002, R24001, R24002, R25001, R25002, R30001, R30002, R32001, R32002, R33001, R33002, R44001, R44002: 3.3k 1%; R_0402_1005Metric
R19002, R26002, R27002, R33004, R38001, R39001, R39003, R40001, R42001: 49.9; R_0805_2012Metric
U1, U2, U3, U4: NTJD4001NT1G; SOT-363_SC-70-6
U5001, U8001, U9001, U14001, U15001, U16001, U17001, U18001, U20001, U21001, U24001, U25001, U30001, U32001, U33001, U44001: OPA333xxDBV; SOT-23-5
U19001, U26001, U27001, U33002, U38001, U39001, U39002, U40001, U42001: 74LVC1G17; SOT-23-5

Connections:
+1V024: C6.2, C12.2, IC1.6 (REF), IC2.6 (REF)
+2V5: IC13.3 (+IN), IC14.3 (+IN), IC16.3 (+IN), IC17.3 (+IN), IC19.3 (+IN), IC20.3 (+IN), IC22.3 (+IN), IC23.3 (+IN)
+3V3: C4.1, C10.1, C26.2, C29.2, C32.2, C35.2, C55.1, C58.1, C66.1, C69.1, C77.1, C80.1, C88.1, C91.1, C5003.2, C8003.2, C9003.2, C14003.2, C15003.2, C16003.2, C17003.2, C18003.2, C19001.2, C20003.2, C21003.2, C22001.2, C23001.2, C24003.2, C25003.2, C26001.2, C27001.2, C27004.2, C30003.2, C31001.2, C32004.2, C32005.2, C33004.2, C33005.2, C34002.2, C37001.2, C38001.2, C39001.2, C39002.2, C40001.2, C42001.2, C44003.2, C45001.2, D7.2 (A), D8.2 (A), D9.2 (A), D10.2 (A), IC1.8 (+VS), IC2.8 (+VS), IC5.8 (+VS), IC6.8 (+VS), IC7.8 (+VS), IC8.8 (+VS), IC13.5 (V+), IC14.5 (V+), IC16.5 (V+), IC17.5 (V+), IC19.5 (V+), IC20.5 (V+), IC22.5 (V+), IC23.5 (V+), IC22001.8 (+VS), IC23001.8 (+VS), IC27001.8 (+VS), IC31001.8 (+VS), IC32002.8 (+VS), IC34002.8 (+VS), IC37001.8 (+VS), IC45001.8 (+VS), U5001.5 (V+), U8001.5 (V+), U9001.5 (V+), U14001.5 (V+), U15001.5 (V+), U16001.5 (V+), U17001.5 (V+), U18001.5 (V+), U19001.5 (VCC), U20001.5 (V+), U21001.5 (V+), U24001.5 (V+), U25001.5 (V+), U26001.5 (VCC), U27001.5 (VCC), U30001.5 (V+), U32001.5 (V+), U33001.5 (V+), U33002.5 (VCC), U38001.5 (VCC), U39001.5 (VCC), U39002.5 (VCC), U40001.5 (VCC), U42001.5 (VCC), U44001.5 (V+)
+12V: C52.1, C63.1, C74.1, C85.1, IC12.8 (+VS), IC15.8 (+VS), IC18.8 (+VS), IC21.8 (+VS), IC1003.8 (VCC)
+24V: IC1002.8 (VCC), IC32001.8 (VCC), IC33001.8 (VCC), IC34001.8 (VCC), IC35001.8 (VCC)
/4-20mA Frontend1/+24_EXC: C33001.2, IC33001.1 (VO), J1004.8
/4-20mA Frontend1/SIGNAL: IC6.4 (+IN), J1004.9, R24.2, R25.2
/4-20mA Frontend1/sallen_key_3kHz3/VIN: IC6.7 (VOUT), R30001.1
/4-20mA Frontend2/+24_EXC: C34001.2, IC34001.1 (VO), J1004.5
/4-20mA Frontend2/SIGNAL: IC7.4 (+IN), J1004.6, R26.2, R27.2
/4-20mA Frontend2/sallen_key_3kHz3/VIN: IC7.7 (VOUT), R32001.1
/4-20mA Frontend3/+24_EXC: C35001.2, IC35001.1 (VO), J1004.2
/4-20mA Frontend3/SIGNAL: IC8.4 (+IN), J1004.3, R28.2, R29.2
/4-20mA Frontend3/sallen_key_3kHz3/VIN: IC8.7 (VOUT), R33001.1
/4-20mA Frontend/+24_EXC: C32001.2, IC32001.1 (VO), J1004.11
/4-20mA Frontend/SIGNAL: IC5.4 (+IN), J1004.12, R22.2, R23.2
/4-20mA Frontend/sallen_key_3kHz3/VIN: IC5.7 (VOUT), R16001.1
/AIN2: C20002.2, U20001.1, U20001.4 (-)
/AIN3: C16002.2, U16001.1, U16001.4 (-)
/AIN4: C30002.2, U30001.1, U30001.4 (-)
/AIN5: C32003.2, U32001.1, U32001.4 (-)
/AIN6: C33003.2, U33001.1, U33001.4 (-)
/AIN7: C15002.2, U15001.1, U15001.4 (-)
/AIN8: C17002.2, U17001.1, U17001.4 (-)
/AIN9: C18002.2, U18001.1, U18001.4 (-)
/AIN10: C5002.2, U5001.1, U5001.4 (-)
/AIN11: C8002.2, U8001.1, U8001.4 (-)
/AIN12: C21002.2, U21001.1, U21001.4 (-)
/AIN13_DAC0: IC37001.4 (+IN), R37001.1
/AIN14_DAC1: IC34002.4 (+IN), R34001.1
/AIN15: C25002.2, U25001.1, U25001.4 (-)
/AIN16: C44002.2, U44001.1, U44001.4 (-)
/AIN17: C24002.2, U24001.1, U24001.4 (-)
/AIN18: C9002.2, U9001.1, U9001.4 (-)
/AIN19: C14002.2, U14001.1, U14001.4 (-)
/K-Type TC Amp1/Signal+: C7.1, C8.1, IC2.4 (+IN), R7.2
/K-Type TC Amp1/Signal-: C8.2, C9.1, IC2.1 (-IN1), R8.1, R9.1
/K-Type TC Amp1/sallen_key_1kHz/VIN: IC2.7 (VOUT), R8001.1
/K-Type TC Amp/Signal+: C1.1, C2.1, IC1.4 (+IN), R2.2
/K-Type TC Amp/Signal-: C2.2, C3.1, IC1.1 (-IN1), R3.1, R4.1
/K-Type TC Amp/sallen_key_1kHz/VIN: IC1.7 (VOUT), R5001.1
/PWM0: R33003.1, U33002.2
/PWM1: R19001.1, U19001.2
/PWM2: R26001.1, U26001.2
/PWM3: R27001.1, U27001.2
/RTD Amp1/R+: J1006.6, R59.2
/RTD Amp1/R-: J1006.5, R60.2, U3.3 (D2)
/RTD Amp1/W-: J1006.4, R61.2, U3.6 (D1)
/RTD Amp1/rtd_amp_inner/Signal+: C71.2, C72.1, IC18.4 (+IN), R60.1
/RTD Amp1/rtd_amp_inner/Signal-: C72.2, C73.1, IC18.1 (-IN1), R61.1
/RTD Amp1/rtd_amp_inner/Vout: D46001.1 (K), IC18.7 (VOUT), R17001.1
/RTD Amp2/R+: J1006.3, R68.2
/RTD Amp2/R-: J1006.2, R69.2, U4.3 (D2)
/RTD Amp2/W-: J1006.1, R70.2, U4.6 (D1)
/RTD Amp2/rtd_amp_inner/Signal+: C82.2, C83.1, IC21.4 (+IN), R69.1
/RTD Amp2/rtd_amp_inner/Signal-: C83.2, C84.1, IC21.1 (-IN1), R70.1
/RTD Amp2/rtd_amp_inner/Vout: D47001.1 (K), IC21.7 (VOUT), R18001.1
/RTD Amp/R+: J1006.9, R41.2
/RTD Amp/R-: J1006.8, R42.2, U1.3 (D2)
/RTD Amp/W-: J1006.7, R43.2, U1.6 (D1)
/RTD Amp/rtd_amp_inner/Signal+: C49.2, C50.1, IC12.4 (+IN), R42.1
/RTD Amp/rtd_amp_inner/Signal-: C50.2, C51.1, IC12.1 (-IN1), R43.1
/RTD Amp/rtd_amp_inner/Vout: D45001.1 (K), IC12.7 (VOUT), R15001.1
/ain_0-15V_1/VIN: J1005.6, R23001.2
/ain_0-15V_1/sallen_key_3kHz8/VIN: IC23001.7 (VOUT), R24001.1
/ain_0-15V_/VIN: J1005.8, R45004.2
/ain_0-15V_/sallen_key_3kHz8/VIN: IC45001.7 (VOUT), R44001.1
/ain_g1_1/VIN: IC22001.4 (+IN), J1005.10, R22001.1
/ain_g1_1/sallen_key_3kHz7/VIN: IC22001.7 (VOUT), R25001.1
/ain_g1_/VIN: IC27001.4 (+IN), J1005.12, R27003.1
/ain_g1_/sallen_key_3kHz7/VIN: IC27001.7 (VOUT), R21001.1
/ain_g25p7_/VIN: IC31001.4 (+IN), J1005.4, R31002.1
/ain_g25p7_/sallen_key_1kHz2/VIN: IC31001.7 (VOUT), R9001.1
/ain_g666p333_/VIN: IC32002.4 (+IN), J1005.2, R32004.1
/ain_g666p333_/sallen_key_100Hz1/VIN: IC32002.7 (VOUT), R14001.2
/dac_buf1/VOUT: IC34002.7 (VOUT), J1001.4
/dac_buf/VOUT: IC37001.7 (VOUT), J1001.2
/pwm_in_buf1/VIN: J1003.2, R38001.1
/pwm_in_buf2/VIN: J1003.10, R39003.1
/pwm_in_buf3/VIN: J1003.8, R40001.1
/pwm_in_buf4/VIN: J1003.6, R42001.1
/pwm_in_buf/VIN: J1003.4, R39001.1
/pwm_out_buf1/VOUT: J1001.8, R19002.2
/pwm_out_buf2/VOUT: J1001.10, R26002.2
/pwm_out_buf3/VOUT: J1001.12, R27002.2
/pwm_out_buf/VOUT: J1001.6, R33004.2
/rtd_amp_inner1/250uA_SINK_1: R1.1, R52.2, U2.6 (D1)
/rtd_amp_inner1/250uA_SINK_2: R1.2, R50.2, R51.2, U2.3 (D2)
/rtd_amp_inner1/Signal+: C60.2, C61.1, IC15.4 (+IN), R51.1
/rtd_amp_inner1/Signal-: C61.2, C62.1, IC15.1 (-IN1), R52.1
/rtd_amp_inner1/Vout: D44001.1 (K), IC15.7 (VOUT), R20002.2
GND: C1.2, C3.2, C4.2, C6.1, C7.2, C9.2, C10.2, C12.1, C25.2, C26.1, C28.2, C29.1, C31.2, C32.1, C34.2, C35.1, C49.1, C51.2, C52.2, C55.2, C58.2, C60.1, C62.2, C63.2, C66.2, C69.2, C71.1, C73.2, C74.2, C77.2, C80.2, C82.1, C84.2, C85.2, C88.2, C91.2, C1001.1, C1002.1, C1003.1, C5001.1, C5003.1, C8001.1, C8003.1, C9001.1, C9003.1, C14001.1, C14003.1, C15001.1, C15003.1, C16001.1, C16003.1, C17001.1, C17003.1, C18001.1, C18003.1, C19001.1, C20001.1, C20003.1, C21001.1, C21003.1, C22001.1, C23001.1, C24001.1, C24003.1, C25001.1, C25003.1, C26001.1, C27001.1, C27004.1, C30001.1, C30003.1, C31001.1, C32001.1, C32002.1, C32004.1, C32005.1, C33001.1, C33002.1, C33004.1, C33005.1, C34001.1, C34002.1, C35001.1, C37001.1, C38001.1, C39001.1, C39002.1, C40001.1, C42001.1, C44001.1, C44003.1, C45001.1, D19001.2 (A), D26001.2 (A), D27001.2 (A), D33001.2 (A), D38001.2 (A), D39001.2 (A), D39002.2 (A), D40001.2 (A), D42001.2 (A), D44001.2 (A), D45001.2 (A), D46001.2 (A), D47001.2 (A), IC1.5 (-VS), IC2.5 (-VS), IC5.1 (-IN1), IC5.5 (-VS), IC5.6 (REF), IC6.1 (-IN1), IC6.5 (-VS), IC6.6 (REF), IC7.1 (-IN1), IC7.5 (-VS), IC7.6 (REF), IC8.1 (-IN1), IC8.5 (-VS), IC8.6 (REF), IC12.5 (-VS), IC12.6 (REF), IC13.2 (V-), IC14.2 (V-), IC15.5 (-VS), IC15.6 (REF), IC16.2 (V-), IC17.2 (V-), IC18.5 (-VS), IC18.6 (REF), IC19.2 (V-), IC20.2 (V-), IC21.5 (-VS), IC21.6 (REF), IC22.2 (V-), IC23.2 (V-), IC1001.5 (ADJ_/_EN), IC1001.6 (GND), IC1002.5 (ADJ_/_EN), IC1002.6 (GND), IC1003.5 (ADJ_/_EN), IC1003.6 (GND), IC22001.1 (-IN1), IC22001.5 (-VS), IC22001.6 (REF), IC23001.1 (-IN1), IC23001.5 (-VS), IC23001.6 (REF), IC27001.1 (-IN1), IC27001.5 (-VS), IC27001.6 (REF), IC31001.1 (-IN1), IC31001.5 (-VS), IC31001.6 (REF), IC32001.5 (ADJ_/_EN), IC32001.6 (GND), IC32002.1 (-IN1), IC32002.5 (-VS), IC32002.6 (REF), IC33001.5 (ADJ_/_EN), IC33001.6 (GND), IC34001.5 (ADJ_/_EN), IC34001.6 (GND), IC34002.1 (-IN1), IC34002.5 (-VS), IC34002.6 (REF), IC35001.5 (ADJ_/_EN), IC35001.6 (GND), IC37001.1 (-IN1), IC37001.5 (-VS), IC37001.6 (REF), IC45001.1 (-IN1), IC45001.5 (-VS), IC45001.6 (REF), J1001.1, J1001.3, J1001.5, J1001.7, J1001.9, J1001.11, J1003.1, J1003.3, J1003.5, J1003.7, J1003.9, J1004.1, J1004.4, J1004.7, J1004.10, J1005.1, J1005.3, J1005.5, J1005.7, J1005.9, J1005.11, J1007.1, J1007.3, J1007.5, J1007.7, J1007.9, J1007.11, R4.2, R9.2, R23.1, R25.1, R27.1, R29.1, R44.2, R47.2, R53.2, R56.2, R62.2, R65.2, R71.2, R74.2, R19001.2, R22001.2, R23002.2, R26001.2, R27001.2, R27003.2, R31002.2, R32004.2, R33003.2, R34001.2, R37001.2, R38002.2, R39002.2, R39004.2, R40002.2, R42002.2, R45003.2, U5001.2 (V-), U8001.2 (V-), U9001.2 (V-), U14001.2 (V-), U15001.2 (V-), U16001.2 (V-), U17001.2 (V-), U18001.2 (V-), U19001.3 (GND), U20001.2 (V-), U21001.2 (V-), U24001.2 (V-), U25001.2 (V-), U26001.3 (GND), U27001.3 (GND), U30001.2 (V-), U32001.2 (V-), U33001.2 (V-), U33002.3 (GND), U38001.3 (GND), U39001.3 (GND), U39002.3 (GND), U40001.3 (GND), U42001.3 (GND), U44001.2 (V-)
unnamed: C25.1, R22.1
unnamed: C28.1, R24.1
unnamed: C31.1, R26.1
unnamed: C34.1, R28.1
unnamed: C5002.1, R5001.2, R5002.1
unnamed: C8002.1, R8001.2, R8002.1
unnamed: C9002.1, R9001.2, R9002.1
unnamed: C14002.1, R14001.1, R14002.2
unnamed: C15002.1, R15001.2, R15002.1
unnamed: C16002.1, R16001.2, R16002.1
unnamed: C17002.1, R17001.2, R17002.1
unnamed: C18002.1, R18001.2, R18002.1
unnamed: C20002.1, R20001.2, R20002.1
unnamed: C21002.1, R21001.2, R21002.1
unnamed: C24002.1, R24001.2, R24002.1
unnamed: C25002.1, R25001.2, R25002.1
unnamed: C30002.1, R30001.2, R30002.1
unnamed: C32003.1, R32001.2, R32002.1
unnamed: C33003.1, R33001.2, R33002.1
unnamed: C44002.1, R44001.2, R44002.1
unnamed: D7.1 (K), R41.1
unnamed: D8.1 (K), R50.1
unnamed: D9.1 (K), R59.1
unnamed: D10.1 (K), R68.1
unnamed: D19001.1 (K), R19002.1, U19001.4
unnamed: D26001.1 (K), R26002.1, U26001.4
unnamed: D27001.1 (K), R27002.1, U27001.4
unnamed: D33001.1 (K), R33004.1, U33002.4
unnamed: D38001.1 (K), R38001.2, R38002.1, U38001.2
unnamed: D39001.1 (K), R39001.2, R39002.1, U39001.2
unnamed: D39002.1 (K), R39003.2, R39004.1, U39002.2
unnamed: D40001.1 (K), R40001.2, R40002.1, U40001.2
unnamed: D42001.1 (K), R42001.2, R42002.1, U42001.2
unnamed: IC1.2 (RG_1), R6.1
unnamed: IC1.3 (RG_2), R6.2
unnamed: IC2.2 (RG_1), R11.1
unnamed: IC2.3 (RG_2), R11.2
unnamed: IC12.2 (RG_1), R40.1
unnamed: IC12.3 (RG_2), R40.2
unnamed: IC13.4 (-IN), R44.1, U1.1 (S1)
unnamed: IC13.1 (OUT), U1.2 (G1)
unnamed: IC14.4 (-IN), R47.1, U1.4 (S2)
unnamed: IC14.1 (OUT), U1.5 (G2)
unnamed: IC15.2 (RG_1), R49.1
unnamed: IC15.3 (RG_2), R49.2
unnamed: IC16.4 (-IN), R53.1, U2.1 (S1)
unnamed: IC16.1 (OUT), U2.2 (G1)
unnamed: IC17.4 (-IN), R56.1, U2.4 (S2)
unnamed: IC17.1 (OUT), U2.5 (G2)
unnamed: IC18.2 (RG_1), R58.1
unnamed: IC18.3 (RG_2), R58.2
unnamed: IC19.4 (-IN), R62.1, U3.1 (S1)
unnamed: IC19.1 (OUT), U3.2 (G1)
unnamed: IC20.4 (-IN), R65.1, U3.4 (S2)
unnamed: IC20.1 (OUT), U3.5 (G2)
unnamed: IC21.2 (RG_1), R67.1
unnamed: IC21.3 (RG_2), R67.2
unnamed: IC22.4 (-IN), R71.1, U4.1 (S1)
unnamed: IC22.1 (OUT), U4.2 (G1)
unnamed: IC23.4 (-IN), R74.1, U4.4 (S2)
unnamed: IC23.1 (OUT), U4.5 (G2)
unnamed: C1001.2, IC1001.1 (VO), J1007.2, J1007.4
unnamed: C1002.2, IC1002.1 (VO), J1007.10, J1007.12
unnamed: C1003.2, IC1003.1 (VO), J1007.6, J1007.8
unnamed: IC23001.4 (+IN), R23001.1, R23002.1
unnamed: IC31001.2 (RG_1), R31001.1
unnamed: IC31001.3 (RG_2), R31001.2
unnamed: IC32002.2 (RG_1), R32003.1
unnamed: IC32002.3 (RG_2), R32003.2
unnamed: IC45001.4 (+IN), R45003.1, R45004.1
unnamed: J12.1, R3.2
unnamed: J12.2, R2.1
unnamed: J13.1, R8.2
unnamed: J13.2, R7.1
unnamed: C5001.2, R5002.2, U5001.3 (+)
unnamed: C8001.2, R8002.2, U8001.3 (+)
unnamed: C9001.2, R9002.2, U9001.3 (+)
unnamed: C14001.2, R14002.1, U14001.3 (+)
unnamed: C15001.2, R15002.2, U15001.3 (+)
unnamed: C16001.2, R16002.2, U16001.3 (+)
unnamed: C17001.2, R17002.2, U17001.3 (+)
unnamed: C18001.2, R18002.2, U18001.3 (+)
unnamed: C20001.2, R20001.1, U20001.3 (+)
unnamed: C21001.2, R21002.2, U21001.3 (+)
unnamed: C24001.2, R24002.2, U24001.3 (+)
unnamed: C25001.2, R25002.2, U25001.3 (+)
unnamed: C30001.2, R30002.2, U30001.3 (+)
unnamed: C32002.2, R32002.2, U32001.3 (+)
unnamed: C33002.2, R33002.2, U33001.3 (+)
unnamed: C44001.2, R44002.2, U44001.3 (+)

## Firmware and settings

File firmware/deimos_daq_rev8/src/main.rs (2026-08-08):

//! Peripheral side of control program
#![no_main]
#![no_std]

mod board;

extern crate alloc;
extern crate cortex_m;
extern crate cortex_m_rt as rt;

use embedded_alloc::LlffHeap as Heap;
use rt::{entry, exception};
use stm32h7xx_hal::stm32;

use core::mem::{MaybeUninit, size_of};
use core::panic::PanicInfo;
use core::ptr::{addr_of, addr_of_mut, copy_nonoverlapping};
use core::sync::atomic::compiler_fence;

use irq::{handler, scope};
use smoltcp::{iface::SocketStorage, storage::PacketMetadata};

use crate::board::{Board, subsystems::net::NetStorageStatic};

#[global_allocator]
static HEAP: Heap = Heap::empty();

// Link region markers.
// These are placed at the start/end of special link regions
// to give us a way to refer to them at run time.
unsafe extern "C" {
    static _heap_start: u8;
    static _heap_size: u8;
    static __siitcm: u32; // Sampler DSP procedure function pointer
    static mut __sitcm: u32; // Start of ITCM interrupt memory region
    static mut __eitcm: u32; // End of ITCM
}

/// Move sensitive functions into ITCM (Instruction Tightly-Coupled Memory)
unsafe fn initialize_itcm() {
    let source = addr_of!(__siitcm);
    let start = addr_of_mut!(__sitcm);
    let end = addr_of_mut!(__eitcm);
    let words = (end as usize - start as usize) / size_of::<u32>();

    // Move sampler DSP procedure from flash into ITCM
    // so that it can't be ejected from L1 cache.
    unsafe {
        copy_nonoverlapping(source, start, words);
    }

    cortex_m::asm::dsb();
    cortex_m::asm::isb();
}

// MaybeUninit allows us write code that is correct even if STORE is not
// initialised by the runtime
static mut STORE: MaybeUninit<NetStorageStatic> = MaybeUninit::uninit();

/// User entrypoint after cortex-m-rt initializes `.data` and `.bss`.
///
/// Copies the sampling routine into ITCM before interrupts can execute it.
#[entry]
unsafe fn main() -> ! {
    unsafe {
        initialize_itcm();
    }

    // Initialize runtime-defined exception handlers before running any
    // application code or doing anything that might trigger them
    handler!(systick_default_handler = || {});

    unsafe {
        HEAP.init(
            core::ptr::addr_of!(_heap_start) as usize,
            core::ptr::addr_of!(_heap_size) as usize,
        );
    }

    // Initialize static storage
    // unsafe: mutable reference to static storage, we only do this once
    let store: &mut NetStorageStatic<'_> = unsafe {
        let store_ptr = addr_of_mut!(STORE);

        // Write the full storage block through a raw pointer so the static
        // itself is never borrowed mutably.
        (*store_ptr).write(NetStorageStatic {
            socket_storage: [SocketStorage::EMPTY; 8],
            rx_metadata_storage: [PacketMetadata::EMPTY; 4],
            rx_payload_storage: [0u8; 1522],
            tx_metadata_storage: [PacketMetadata::EMPTY; 4],
            tx_payload_storage: [0u8; 1522],
            tcp_rx_storage: [0u8; 512],
            tcp_tx_storage: [0u8; 512],
        });

        // Now that the value is fully initialised we can obtain the unique
        // mutable reference that startup passes into Board::new.
        (*store_ptr).assume_init_mut()
    };

    // Board startup
    let (mut board, mut sampler) = Board::new(store);

    // Stack-watermark test images can paint unused MSP memory immediately
    // before the interrupt scopes begin. A debugger later scans the DTCM
    // pattern, so the diagnostic adds no work to either realtime IRQ.
    // Production builds omit it.
    #[cfg(feature = "stack-watermark")]
    cortex_m_stack::repaint_stack();

    scope(|systick_default| {
        // The state machine lends the sampler to the operating SysTick scope;
        // this outer scope supplies the fallback handler between states.
        systick_default.register(board::interrupts::SysTick, systick_default_handler);
        board.run(&mut sampler);
    });

    loop {}
}

// #[interrupt]
// fn ETH() {
//     unsafe { ethernet::interrupt_handler() }
// }

#[exception]
unsafe fn HardFault(_ef: &cortex_m_rt::ExceptionFrame) -> ! {
    panic!();
}

#[exception]
unsafe fn DefaultHandler(_irqn: i16) {
    // panic!("Unhandled exception (IRQn = {})", irqn);
}

#[panic_handler]
fn panic(_info: &PanicInfo) -> ! {
    // Disable all interrupts, then reset

    cortex_m::interrupt::disable();
    let dp = unsafe { stm32::Peripherals::steal() };

    // Reset the eth mac, which is, by default, not reset by the CPU reset
    // because it's on domain 2
    dp.RCC.ahb1rstr.write(|w| w.eth1macrst().set_bit());

    // Data-and-instruction sync barrier to make sure the eth mac enters reset before the CPU
    cortex_m::asm::dsb();

    // Reset the CPU and restart the program
    dp.RCC.ahb3rstr.write(|w| w.cpurst().set_bit());

    // Data-and-instruction sync barrier to make sure the reset is written before busywaiting
    cortex_m::asm::dsb();

    // Must not return, but is in CPU reset now & program will restart from main
    loop {
        // Don't let the compiler move the loop before writing reset, which it could do to save time
        compiler_fence(core::sync::atomic::Ordering::SeqCst);
    }
}

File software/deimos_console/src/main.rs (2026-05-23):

//! Operator console viewer for Deimos realtime reporting.
//!
//! Subscribes to the multicast stream published by a `ReportingDispatcher`, renders scrolling
//! traces for configured channel groups, and writes a per-session forensic CSV. Connection health
//! is shown in the status bar; use Freeze to inspect a moment without interrupting data
//! collection. See the crate README for the config-file format.

mod app;
mod config;
mod forensic;
mod receiver;

use std::error::Error;
use std::path::PathBuf;

use clap::Parser;

use app::DeimosConsoleApp;
use config::DeimosConsoleConfig;

#[derive(Parser)]
#[command(
    name = "deimos-console",
    about = "Operator console viewer for Deimos realtime reporting"
)]
struct Cli {
    /// Path to the TOML configuration file (see crate README for fields).
    #[arg(long, short, value_name = "FILE")]
    config: PathBuf,
}

fn main() -> Result<(), Box<dyn Error>> {
    let cli = Cli::parse();

    let config_bytes = std::fs::read_to_string(&cli.config)
        .map_err(|e| format!("failed to read config file {}: {e}", cli.config.display()))?;
    let config: DeimosConsoleConfig = toml::from_str(&config_bytes)
        .map_err(|e| format!("failed to parse config file {}: {e}", cli.config.display()))?;

    eprintln!(
        "[{}] deimos-console: starting, listening on {}:{} (forensic_log={})",
        chrono::Local::now().format("%H:%M:%S%.3f"),
        config.multicast_group,
        config.port,
        config
            .forensic_log_path
            .as_ref()
            .map(|p| p.display().to_string())
            .unwrap_or_else(|| "<disabled>".to_string()),
    );

    let (rx, _recv_handle, counters) = receiver::spawn(&config)
        .map_err(|e| format!("failed to start multicast receiver thread: {e}"))?;

    eframe::run_native(
        "Deimos Console",
        eframe::NativeOptions::default(),
        Box::new(|_cc| Ok(Box::new(DeimosConsoleApp::new(config, rx, counters)))),
    )
    .map_err(|e| format!("eframe error: {e}"))?;

    Ok(())
}

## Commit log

2025-01-19 initial refactoring
    [12v_buck.kicad_sch, 1v024_ref.kicad_sch, 24v_connector.kicad_sch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]
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2025-01-20 Update rev4 fab files (#2)
    [4-20mA.kicad_sch, analog_frontend_panel.kicad_pcb, analog_frontend_panel.kicad_sch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]
2025-01-20 Update BoM ref for TC connectors to individual units (#3)
    [analog_frontend_panel.kicad_pcb, ktype_amp.kicad_sch]
2025-01-20 Regenerate rev4 fab files (#4)
    * Re-generate fab files with new TC BoM ref
    * Update schematic and layout references through top level to capture new BoM references
    [3wire_amp.kicad_sch, analog_frontend_panel.kicad_sch, analog_i.kicad_sch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]
2025-01-22 Prep for publishing (#5)
    * Set cargo metadata
    * Write readmes
    * Resolve most clippy lints
    [mod.rs]
2025-01-23 Feature gate & incremental improvements (#6)
    * Do not attach tsdb module if feature is not selected
    * Resolve clippy lints
    * Improve docs
    [mod.rs]
2025-01-26 Implement socket layer (#8)
    ## 2025-01-26
    ### deimos 0.3.0
    #### Added
    * Add socket module with SuperSocket trait and related types
    * Add implementation of SuperSocket for UDP
    #### Changed
    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
2025-02-01 Implement unix sockets for peripheral comms (#9)
    ## 2025-02-01 deimos 0.4.0, deimos_shared 0.2.0
    ### Added - deimos
    * Add implementation of SuperSocket for unix datagram socket
    * Add non-exhaustive `ControllerCtx` context struct to store growing number of settings
    * Add non-exhaustive `Termination` enum for planned termination criteria
    * Add non-exhaustive `LossOfContactPolicy` enum for choosing reconnect behavior
    * Add `ipc_plugin` example demonstrating use of peripheral plugins, a software-defined peripheral state machine, and use of unix socket for communication with a software-defined peripheral
    * Add `dispatcher::fmt_time` method to reduce repeated code for fixed-width UTC fo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
    [pt100_rtd_din-43-760.csv, type_k_its90_csv_from_tab.csv, type_k_its90_mod.csv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]
2025-02-01 Add script file artifacts (#10)
    Add file outputs from scripts. No change to hardware, firmware, or software.
    [pt100_rtd_din-43-760.csv, type_k_its90_csv_from_tab.csv, type_k_its90_mod.csv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]
2025-02-02 Analog I Rev 4 firmware (#11)
    ## 2025-02-02 deimos 0.5.0, deimos_shared 0.3.0, firmware analog_i_rev4
    0.1.0
    * Add AnalogIRev4 peripheral implementation
    ### Changed - deimos
    * Rename `analog_i_rev3` example to `multi_daq` and add an AnalogIRev4
    * Specify mode explicitly in config packet
    * Start clock for binding just before transmission & remove 1ms pad
    * Update function signature for SuperSocket::update_map to be fallible
    * This provides a means to handle errors for duplicate addresses
    * Update UDP and unix socket implementations to check for duplicate
    addresses when building address table
    ### Added - deimos_shared
    * Add AnalogIRev4 packet form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
    [configuring.rs, main.rs, mod.rs]
2025-02-03 Analog I Rev 4.0.1 (#12)
    ## 2025-02-02 Hardware - Analog I Rev 4.0.1
    ### Changed - Hardware - Analog I Rev 4.0.1
    * Replace input comparators with TLV3201s with 1M input pulldown to
    resolve inadequate drive strength
    * Non-inverting hysteresis-free configuration
    * Move screw terminal inward and place silkscreen terminal labels on the
    outside
    * Slightly widen board to make room for labels
    * Update 3 pin screw terminal footprint for more accurate courtyard
    * Update silkscreen labels to orient outward or toward the side opposite
    the power/eth plugs
    [3wire_amp.kicad_sch, 4-20mA.kicad_sch, analog_frontend_panel.kicad_pcb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]
2025-02-05 Implement user channels (#13)
    ## 2025-02-04 deimos 0.5.1
    ### Added
    * Implement user channels
    * Bidirectional multiple-producer, multiple-consumer buffering message
    pipes
    * Passed to appendages with context during init
    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
2025-02-07 Implement dataframe dispatcher (#14)
    ## 2025-02-05 deimos 0.6.0
    * Add `DataFrameDispatcher` for writing data to in-memory dataframe
    * Add `Msg::Packet(Vec<u8>)` variant of user channel message to enable
    generic packetized message-passing
    * !Add `terminate` method to `Dispatcher` and `Calc` traits and
    `Orchestrator` struct
    * To be called when the controller terminates, returning dispatchers to
    their pre-init state for reuse
    ### Changed
    * !Rename `Panic` variant of `Overflow` to `Error`
    * Dispatchers can return an error on consuming values; this provides
    more flexibility in future error handling
    * !Rename `initialize` method of `Dispatcher` trait to `init`
    * !Re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
    [mod.rs]
2025-02-22 Analog I 4.0.1 Firmware (#16)
    ## 2025-02-22 deimos 0.6.2, deimos_shared 0.4.0
    * !Remove duty cycle measurement from Analog I Rev4 firmware, packet
    format, and calcs
    * Despite deconflicting the duty cycle measurement to a different
    compare-and-capture and its own pin, configuring TIM4's second CCMR for
    duty cycle measurement causes both CCMR1 and CCMR2 to fail to trigger
    * This is the only remaining timer module with a second pin or
    compatible second compare-and-capture available, so duty cycle
    measurement will not be available on this unit
    * Relicense under MIT/Apache-2.0 from 0BSD/Apache-2.0
    * Update readme to be more concise
    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
    [mod.rs, operating.rs, sampling.rs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]
2025-02-22 Analog I Rev 4.0.2 (#17)
    ## 2025-02-22 Hardware - Analog I Rev 4.0.2
    * Replace input comparators with SN74LV Schmitt trigger logic buffers
    * Adds about 0.5V hysteresis to resolve jitter & eliminates exposure of
    1V024 ref to noise from digital signals
    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
    [24v_connector.kicad_sch, analog_frontend_panel.kicad_pcb, analog_frontend_panel.kicad_sch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]
2025-02-23 Put optional functionality behind features (#18)
    ## 2025-02-23 deimos 0.7.0
    Place functionality not required to run the base control program behind
    feature flags,
    including serialization, user channels, and manipulation of thread
    priority and core affinity.
    This reduces the base set of deps to 21, only 8 of which are not either
    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
2025-03-24 Implement lookup-table state machines (#19)
    ## 2025-03-23 deimos 0.8.0
    Implement `SequenceMachine` calc, which provides arbitrary lookup-table
    state machines in order to support
    user-defined scheduling and operational logic.
    * !Make `ser` a default feature
    * Make serde_json part of `ser` feature
    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
    [high.csv, low.csv]
2025-05-03 Changes to support editor implementation (#20)
    ## 2025-05-03 deimos 0.8.1
    Edits to prep for implementation of a calc node editor GUI.
    * impl Clone for `Box<dyn Calc>` and `Box<dyn Peripheral>` by sending
    for a roundtrip loop through serde_json
    * Supports construction from prototype in GUI editor
    * Add `kind` methods with default implementation to `Calc` and
    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
2025-06-21 Use alternate filter for very low reporting rate (#24)
    ## 2025-06-21 analog_i_rev4 firmware 0.2.0
    * Add second (butter1) filter bank for low reporting rate to Sampler
    struct
    * Add record of target cutoff ratio to Sampler struct
    * Use second butter1 filter bank if target cutoff ratio is below stable
    range for nominal butter2 filter bank
    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
2025-06-21 Synthetic simultaneous sampling (#26)
    ## 2025-06-21 analog_i_rev4 firmware 0.3.0
    * Implement fractional delay FIR filters on scanned ADC samples to
    produce synthetic simultaneous sampling
    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
2025-06-26 Reduce internal samplerate to 33kHz (#27)
    ## 2025-06-25 analog_i_rev4 firmware 0.4.0, deimos 0.10.1
    * Firmware
    * Update internal samplerate to 33kHz to restore timing margin that was
    lost to fractional delay filters
    * Add accumulated sampling time per comm cycle to cycle timing margin
    metric
    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
2025-08-25 Deimos DAQ Rev 5.0.0 (#28)
    ## 2025-08-25 deimos 0.11.0, deimos_shared 0.5.0, Deimos DAQ Rev 5.0.0
    hardware and firmware
    * Add deimos_daq_rev5 schematic, layout, fab files, and firmware
    * Adds active analog filters, 2x buffered analog outputs, and more raw
    voltage inputs
    * Add deimos_daq_rev5 interface to deimos_shared
    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
    [12v_buck.kicad_sch, 1v024_ref.kicad_sch, 24v_connector.kicad_sch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]
2025-09-20 Deimos DAQ Rev 6.0.0 (#29)
    ## 2025-09-19 Deimos DAQ Rev 6.0.0 hardware and firmware
    Tooling
    * ubuntu 24.04
    * kicad 8 with hierarchical PCB plugin
    * protocase designer v7.2.1 linux version
    * Run like
    `LD_LIBRARY_PATH=/opt/protocasedesigner/lib/app/natives/occjava/linux-x86_64/
    /opt/protocasedesigner/bin/ProtocaseDesigner` to resolve link path issue
    for java runtime
    * freecad 1.0.2
    * Enclosure design (protocase)
    * 3D assembly (freecad)
    * With STEP exports from protocase and kicad
    * Rev6 schematic and layout
    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
    [12v_buck.kicad_sch, 12v_inverting.kicad_sch, 1v024_ref.kicad_sch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]
2025-10-13 Deimos DAQ Rev 6.0.1 (#30)
    ## 2025-10-12 deimos 0.11.2, deimos_shared 0.5.1, Deimos DAQ Rev 6.0.1
    Hardware
    * Deimos DAQ Rev 6.0.1 schematic and layout
    * [x] Replace overvoltage protection diodes from leaky zeners to
    low-leakage JFET clamp
    * [x] Add 5V LDO as supply for resistance amplifiers to restore gate
    voltage margin
    * [x] Use smaller resistor values for resis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
    [12v_buck.kicad_sch, 12v_inverting.kicad_sch, 1v024_ref.kicad_sch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]
2025-10-13 Filter cold-junction temperature (#31)
    ## 2025-10-13 deimos 0.11.3
    * `calc::butter` module with `Butter2` second order butterworth filter
    calc
    * `branches` dep for branch hinting filter initialization
    * Apply 1Hz Butter2 filtered `board_rtd_filtered` channel in rev6
    standard calcs
    * Use filtered board temperature for thermocouple cold-junction
    correction
    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
    [mod.rs]
2025-10-14 Add logging (#32)
    ## 2025-10-13 deimos 0.12.0
    * Add logging module with terminal and file logging setup using
    nonblocking `tracing` ecosystem
    * !Calc trait methods now return Result types
    * !Controller::{bind, scan} now return Result types and map previous
    panic behavior to errors
    * Orchestrator methods map more cases to Err instead of panic
    * Terminal printing in Controller and examples replaced with logging
    * Controller::terminate rolls up all errors before returning
    * In Controller::run, when attempting to send data to dispatchers, an
    attempt is made to send
    data to every dispatcher before returning an error rollup if any errors
    occurred
    * In Controller::run, log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
    [mod.rs]
2025-10-16 Add polynomial calc & improve logging (#33)
    ## 2025-10-14 deimos 0.13.0
    * Add polynomial calc
    * !Make logger guards local instead of global statics to allow
    reconfiguring logging between sequential ops
    * !Return log file location and guards from logger setup
    * Name log file after op
    * Append logs instead of truncating
    * Remove thread priority functionality that requires elevated
    permissions
    * Instead of using every second core for auxiliary functions, reserve
    the first 2 cores
    for the main thread and cycle auxiliary functions over all the remaining
    cores
    * Improve logging and error handling
    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
    [mod.rs]
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2025-10-26 Deimos DAQ Rev 6.0.2 (#35)
    ## 2025-10-26 Deimos DAQ Rev 6.0.2 hardware
    * Deimos DAQ Rev 6
    * Remove trace that bridged 3.3V and 1.024V rails due to autocleanup
    failure during hierarchical layout update
    * Re-generate fab files
    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
2026-01-01 Python bindings (#36)
    ## 2026-01-01 deimos 0.15.0
    Broad refactor and many new features to improve usability of software interface.
    * Rust
    * Add `python` feature for building python bindings
    * Add `controller::nonblocking` module with machinery for running the controller on a separate thread
    * Includes external termination signal and live manual read/write handles
    * Add reconnection logic to controller
    * `LossOfContactPolicy::Reconnect` allows attempting reconnection after losing contact with peripherals during run
    * This provides robustness to IP address reconfiguration, hot-swapping modules, etc
    * Provide a timeout duration or allow i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
2026-01-01 Improve python build (#37)
    * Handle manifest path
    * Remove default features on `branches` that use inline-asm that is not
    available for powerpc python targets
    * Remove 32-bit linux target for now due to crashing CI runner
    [mod.rs]
2026-03-21 Support complex networks (#39)
    ## 2026-03-21 deimos 0.16.0
    * Handle peripheral discovery across multiple eth interfaces or subnets
    * This allows use on routers operating in bridge mode with their own NAT
    layer and subnet
    * Support selecting a specific eth interface or subnet
    * This allows the industrial-style dual-interface where the control
    network is on its own network interface, separated from the global
    internet
    * Add dot/graphviz export for calc orchestrator and sequence machine
    * TSDB dispatcher upgrades
    * Set chunk size for TSDB dispatcher to 25% of retention duration by
    default
    * This resolves disk space errors caused by the database failing to
    clear any stale data due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
    [abort.csv, high.csv]
2026-03-25 Deimos DAQ Rev7 Hardware (#40)
    [12v_buck.kicad_sch, 12v_inverting.kicad_sch, 15EDGKM-3.81-12P-1Y-00A&Z(H).stp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]
2026-04-04 Support direct ethernet connection (#41)
    ## 2026-04-02 deimos 0.16.1, rev7 firmware 0.6.0
    This update continues the buildup of the firmware for the rev7,
    including support for statically-addressed networks without DHCP
    and direct ethernet connection to the control computer.
    While statically-addressed networks assembled using ARP are usually
    limited
    by ARP storm instability, this implementation mitigates that failure
    mode
    by checking a bounded number of candidate addresses instead of broadcast
    scanning.
    For the same reason, no broadcast gratuitous ARP is sent when an address
    is claimed.
    * deimos
    * `peripheral::deimos_daq_rev7` module with updated default calcs
    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
    [configuring.rs, main.rs, mod.rs]
2026-05-02 Add HOOTL examples and DeimosDaqRev7 byte-compat test (#43)
    ## Summary
    Adds a HOOTL lifecycle example and two new tests covering
    `DeimosDaqRev7`
    wire-format compatibility and `Butter2` state reset.
    - `examples/hootl_lifecycle.rs` — full controller lifecycle in-process
    via
    `ThreadChannelSocket`; terminates after 3 s.
    - `peripheral/hootl.rs` byte-compat tests —
    - `test_deimos_daq_rev7_hootl_emit_byte_compat`: outbound
    operating-cycle
    bytes from `HootlPeripheral` are identical to those from a real
    `DeimosDaqRev7`.
    - `test_deimos_daq_rev7_hootl_parse_diverges`: inbound parsed outputs
    differ from the real parse because `HootlPeripheral` fills outputs
    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
2026-05-24 Updates for 0.16.2 release (#49)
    [Deimos_Daq_Rev7_Bare_95p5_x_231_Rev1_as_quoted.step]
2026-06-13 Analytic filter construction (#51)
    ## 2026-06-08 0.17.0
    This update moves the rev7 firmware's filter construction and runtime
    from `flaw` to `deimos_numerics`, and from interpolated to analytic
    construction. The filter construction pipeline is moved to deimos_shared
    and adds access to filter transfer functions on the application side
    that exactly match the ones used by the firmware, along with an example
    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
    [abort.csv]
2026-06-29 Implement calibration (#52)
    ## 2026-06-28 0.18.0
    This update adds calibration procedures for the Rev7 and wires
    calibration handling into the controller, calc orchestrator,
    and peripheral trait. It also adds and ultra-lightweight, open-access
    calibration database as part of the static site, populated with the
    first set of calibrations.
    * Add Rev 7.0.0 calibration procedure
    * Add calibration record structs
    * Remove initial calc evaluation before entering control loop
    * No longer needed, since we now wait until all peripherals have
    responded to start calcs
    * Removing this makes software-side filter initialization instant on
    first cycle
    * Add supporting functions to t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
    [analog_frontend_panel.kicad_sch, micro.kicad_sch, sk_3kHz.kicad_sch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]
2026-07-20 Deimos DAQ Rev 7.0.1 (#57)
    ## 2026-07-19 0.18.1
    * Rev7 hardware
    * Finish pcb layout updates & re-generate fab files
    * Update enclosure graphics
    * Rev7 firmware
    * Move `sample()` function with DSP pipeline into ITCM memory
    * Move `Net::poll` function with bulk of networking logic into ITCM
    * This prevents them from being ejected from cache, or taking up space
    in cache
    * This should allow all remaining Operating-state code to remain in L1
    cache (16kB)
    * Update an example and reqwest dep
    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
    [analog_frontend_panel.kicad_pcb, analog_i.kicad_pcb]
2026-07-31 Deimos DAQ Rev 7.0.2 (#59)
    * Remove cathode cap from shunt reg to restore stability
    * Update layout and fab files
    * Add as-ordered enclosure with eth cutout mod from protocase
    * Fix graphics typo on enclosure
    [Deimos Daq Bare 95p5 x 231 Rev7.step, analog_frontend_panel.kicad_pcb, analog_frontend_panel.kicad_sch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]
2026-08-08 Modbus interface (#60)
    ## 2026-08-01 0.19.0
    Firmware overhaul for the Rev7 DAQ.
    * Rev 7.0.2 Hardware
    * Rev7 Firmware 0.8.0
    * Use a more robust synchronous sampling scheme
    * 9kHz synchronous oversampling up to 3kHz
    * Synchronous sampling from 3kHz to 8kHz
    * This gives lower jitter and more well-posed cycle timing margin than
    high-frequency oversampling
    * Add modbus support
    * Characterize cycle timing margin and stack usage
    * Add packet magic numbers and validation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
    [configuring.rs]
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2026-08-15 Rev 7.0.3 hardware (#64)
    ## 2026-08-14 Hardware Rev 7.0.3
    * [x] Flip orientation of IDC header
    * [x] Resolve crosstalk between 35mV channels and thermocouple channels
    * Buffer shared 1.024V offset ref at each 35mV frontend
    * [x] Improve light-pipe LED brightness
    * [x] Improve 24V supply filtering
    * Need better immunity to conducted EMI from the upstream power supply
    * Just added more capacitance for now
    * [x] Exclude testpoints from BOM
    [24v_connector.kicad_sch, ain_g25p7_.kicad_sch, analog_frontend_panel.kicad_pcb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]
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2026-08-23 Improve power input filters (#67)
    * Remove immediate input power caps to eliminate spark on connection
    * Add 220nH filter inductors to each converter
    * Add LCSC ref number to OPA196 schematic symbols
    [12v_buck.kicad_sch, 12v_inverting.kicad_sch, 24v_connector.kicad_sch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]
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2026-09-05 Deimos DAQ Rev8 (#69)
    ## 2026-09-05 Hardware Rev 8.0.0, Software 0.21.1
    Tooling: Same as 6.0.1
    Changes
    * rev7 firmware
    * Use `qei` HAL module to configure encoder
    * Add rev8 firmware
    * Copy forward from rev7
    * Replace frequency and pulse counter inputs with more encoders
    * Use `qei` HAL module to configure encoders
    * Software
    * Add rev8 peripheral modules, packets, and standard calcs
    * Hardware
    * [x] Improve digital inputs with 22k resistor and schottky clamp to
    3.3V
    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
    [12v_buck.kicad_sch, 12v_inverting.kicad_sch, 15EDGKM-3.81-12P-1Y-00A&Z(H).stp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]
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
